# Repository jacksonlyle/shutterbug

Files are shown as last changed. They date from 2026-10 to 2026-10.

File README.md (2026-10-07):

# ShutterBug

A 3D-printed transmissive grating spectrograph, built to capture time-series spectra of a vintage flash bulb.

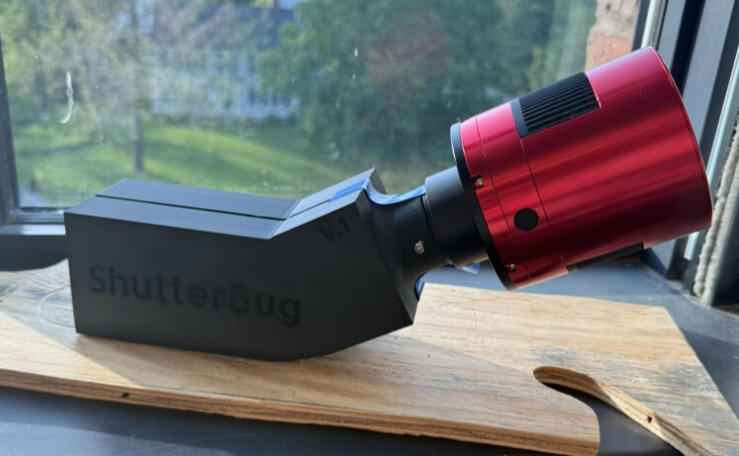
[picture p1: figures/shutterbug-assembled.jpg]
ShutterBug V.1 with a ZWO ASI2600MM Pro attached


The goals for this project were to:

- Create a working spectrograph capable of imaging the visible wavelength range.
- Capture multiple successive spectra of a vintage flash bulb.
- Calibrate and normalize the spectra to identify the bulb's temperature and any absorption lines.

This project was designed around cheap and accessible parts, at the cost of spectral resolution. See
[hardware.md](hardware.md) for the parts list and [docs/reproduce.md](docs/reproduce.md) for build and data reduction steps.

## The Spectrograph

The design began with the transmission grating layout from the Ibsen Photonics
[Spectrometer Design Guide](https://ibsen.com/wp-content/uploads/ebook/spectrometer-resources/Spectrometer-Design-Guide.pdf).
Light enters through a slit, is collimated by a lens, dispersed by the grating, and focused onto the camera sensor.

| Optical path | Design parameters (diagram: Ibsen Photonics) |
|---|---|
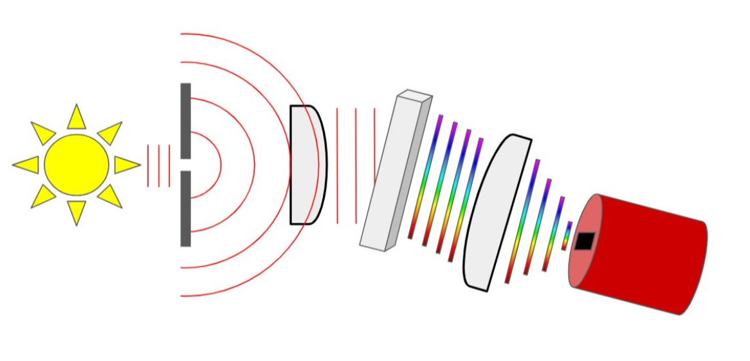
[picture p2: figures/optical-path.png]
Optical path
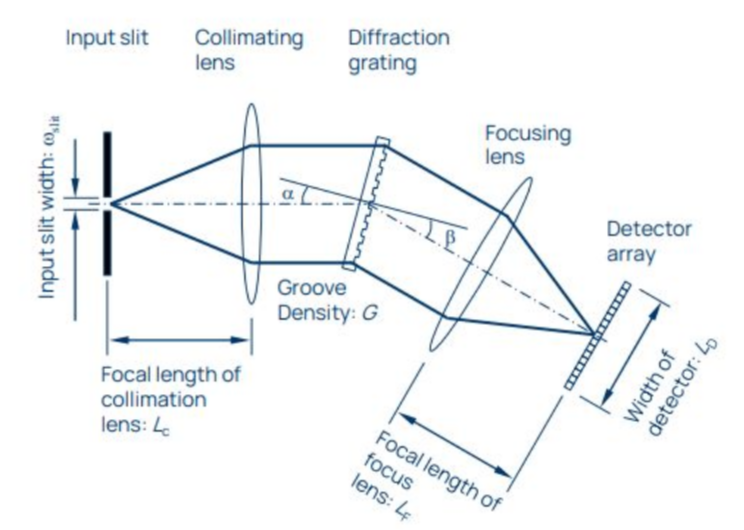
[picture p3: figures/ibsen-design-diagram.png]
Ibsen design diagram
|  |  |

Knowing the size of the camera sensor and my ideal size for the spectrograph, I calculated the distances needed for focus:

| Parameter | Value |
|---|---|
| Groove density, G | 1000 lines/mm |
| Detector width, L_D | 33 mm |
| Angle of incidence, α | 9° |
| Diffraction angle, β | 21° |
| Focus lens focal length, L_F | 103 mm |
| Collimation lens focal length, L_C | 73 mm |
| Slit width, w_slit | 25 µm |

| CAD cutaway | Exterior | Top view |
|---|---|---|
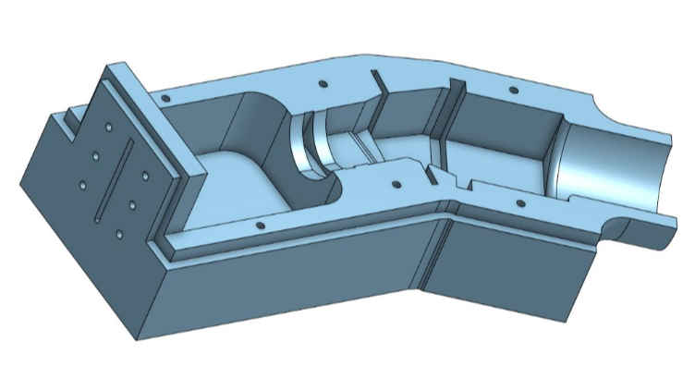
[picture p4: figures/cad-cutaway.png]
CAD cutaway
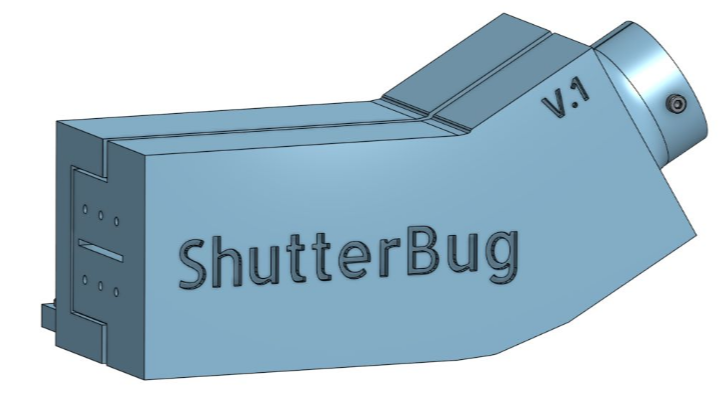
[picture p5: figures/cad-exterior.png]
CAD exterior
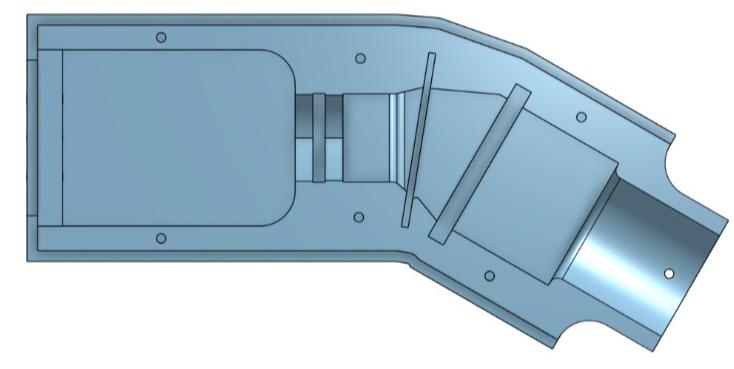
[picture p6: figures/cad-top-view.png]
CAD top view
|  |  |  |

## Obtaining Data

I took data on three sources: the flash bulb itself, a tungsten filament bulb (for flat frames), and an argon emission tube
(for wavelength calibration). SharpCap was used for capture and AstroImageJ for reduction.

The flash lasts approximately 20 ms, and I wanted ~10 individual frames of it. To get there, I imaged a 6248 x 20 pixel
region of the sensor with 1 ms exposures at about 550 FPS. That leaves hundreds of files to sift through, so a short script
kept only the frames above a minimum brightness. I settled on 9 frames of data.

Each light frame was reduced with master bias, dark, and flat frames (100 bias and 100 dark frames were averaged into their masters).

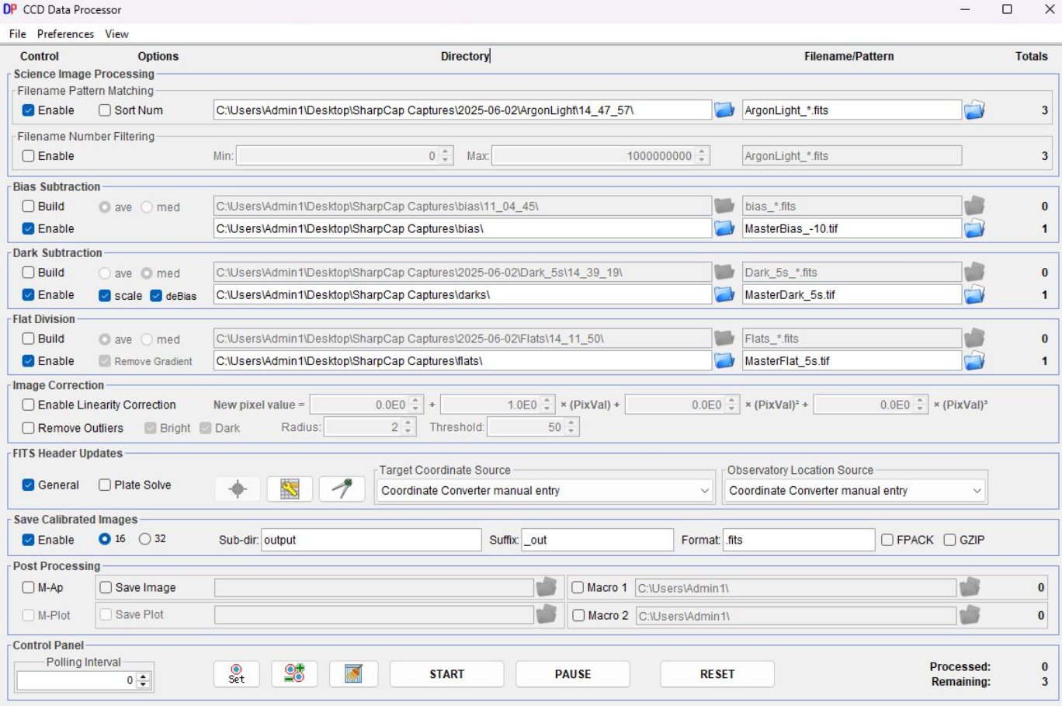
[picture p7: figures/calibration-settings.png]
AstroImageJ CCD Data Processor settings


[spectral_to_csv.py](analysis/spectral_to_csv.py) then averages the central 20 rows of each image into a 1D intensity vs. pixel CSV.

## Calibrating Wavelengths

The argon lamp was dull enough that it needed 5 second exposures instead of 1 ms, so all of the calibration frames had
to be retaken at that length.

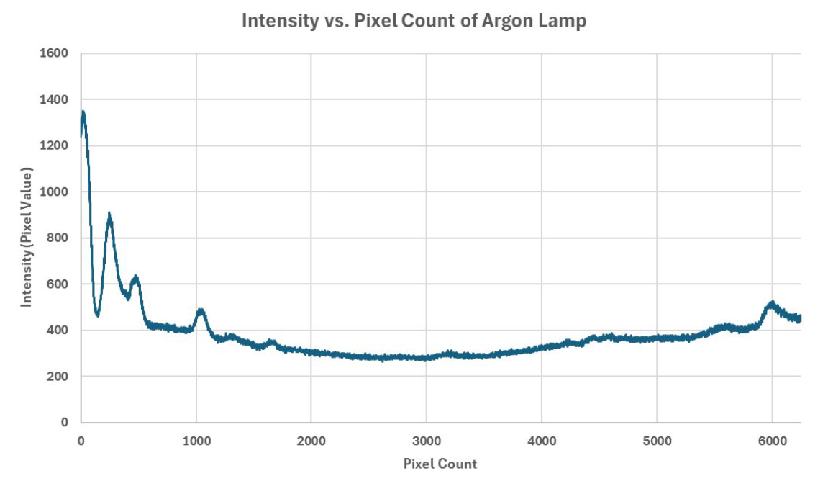
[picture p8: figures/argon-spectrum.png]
Argon lamp intensity vs. pixel count


I identified 7 of the clearest peaks and matched them against Ar I and Ar II lines in the
[NIST Atomic Spectra Database](https://physics.nist.gov/PhysRefData/ASD/lines_form.html). Since the lamp runs at such a high
voltage, it's fair to assume a mixture of neutral and singly ionized argon lines. This gave a (very approximate) linear conversion:

```
wavelength (nm) = 0.06411 * (pixel) + 426.73
```

which puts the spectrograph's range across all 6248 pixels at **426.73–827.29 nm**, a large portion of the visible range.

## Results

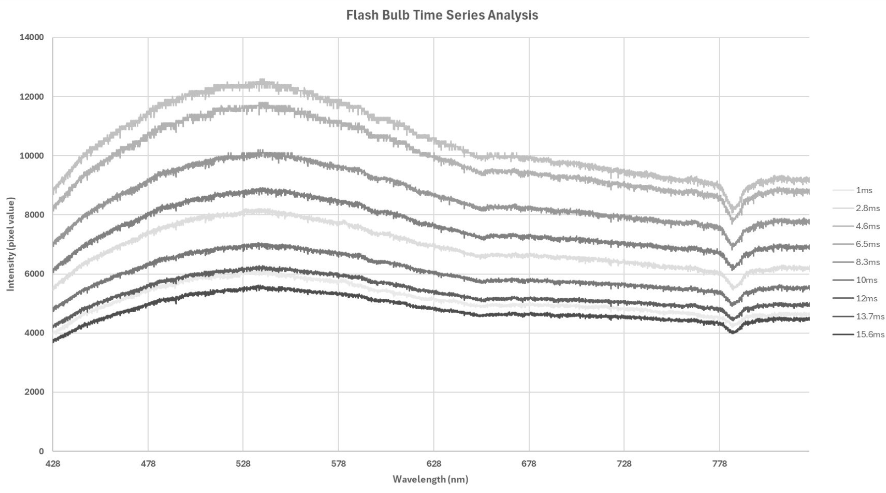
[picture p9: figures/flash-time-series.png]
Flash bulb time series, 1 ms to 15.6 ms


- **Blackbody curve.** Each frame fits a smooth blackbody curve. Using Wien's law on the peak, I estimated a temperature of
  **5470 K**, very close to commonly cited flash bulb values (though sources vary).
- **Time evolution.** The flash brightens over the first few milliseconds, then lowers in intensity and
  flattens. The peak shifts slightly to the right over time, indicating a small drop in temperature over the period of the flash.
- **Absorption.** There are a few small absorption bands and one large broadband absorption region around 780 nm. Based on
  atmospheric absorption data, this matches the O₂ band (the oxygen A-band, ~760 nm), meaning the oxygen in the air between the bulb
  and the slit is absorbing that region. The offset from 760 nm is likely the calibration error described below.

## Sources of Error

- **Quantum efficiency.** I assumed the camera's sensitivity is uniform across wavelengths, when in reality it follows a curve.
  This directly affects the shape of the spectrum, and therefore the Wien's law temperature.
- **Linear calibration.** I assumed the pixel-to-wavelength conversion was linear, when it is closer to a quadratic fit. This was
  apparent in the O₂ band appearing at a longer wavelength than expected.
- **Stray light.** Room lights were on for some of the data capture. I covered any gaps in the spectrograph, but stray light could
  still affect the data.
- **Line identification.** I assumed all argon emission lines were Ar I or Ar II. Other lines in the spectrum would shift the
  conversion and could account for the discrepancy with the measured atmospheric absorption.

The original raw frames and CSVs from this run were not preserved, so the figures above are from the original analysis and the
repository includes the code and build files rather than the data.

## Repository

```
cad/        STEP and STL files for the top plate, bottom plate, and mounting bracket
analysis/   spectral_to_csv.py and requirements.txt
docs/       reproduce.md: build, calibration, and reduction steps
figures/    images used in this README
hardware.md parts list and specifications
```

## Acknowledgements

Thanks to Masaki Muneyoshi for help with the spectrum extraction script.

## Sources

- Ibsen Photonics, [Spectrometer Design Guide](https://ibsen.com/wp-content/uploads/ebook/spectrometer-resources/Spectrometer-Design-Guide.pdf)
- NIST, [Atomic Spectra Database](https://physics.nist.gov/PhysRefData/ASD/lines_form.html)
- [Wien's law](https://boyce-astro.org/wiens-law/), Boyce Research Initiatives and Education Foundation
- ZWO, [ASI2600MM Pro](https://www.zwoastro.com/product/asi2600/)
- FAU, [How the greenhouse effect works](https://www.ces.fau.edu/nasa/module-2/how-greenhouse-effect-works.php)

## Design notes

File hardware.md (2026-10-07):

## Hardware specifications

### Parts List

This project was designed for implementation with cheap and accessible parts, at the cost of spectral resolution.
Most parts for the original project were obtained in a high school physics lab storage, but alternatives can be purchased
from vendors online.

#### Transmissive Grating

The transmissive grating used for this spectrograph was a standard physics lab 1000 lines/mm grating (dimensions fit 
any grating around 50 x 50 x 2 mm in footprint).

#### Lenses 

Based on the geometry of the design, the focal length of the focus lens is 103mm, and the focal length of the collimation
lens is 73mm. 

The focus lens is made for a 50 x 50 x 5 mm footprint lens, and the collimation lens is made for a 25 x 25 x 3.5 mm foorprint lens.

#### Camera

The current camera adapter fits standard 1.25" T mount adapter, available for most DSLR and CCD/CMOS cameras.

PLEASE NOTE: This design was optimized for the ZWO ASI2600MM Pro dimensions and backfocus. You can see details for
the design of this camera and adjust the exact position of a different camera relative to these dimesions: https://www.zwoastro.com/product/new-asi2600mm-mc-pro/ (see "Mechanical Diagram")

#### Fasteners

All of the fasteners are fit for M3 screws:

- 6: M3 x 0.50 x 30
- 6: M3 x 0.50 x 8 (for razor slit)
- 6: M3 x 0.50 nuts
- 2: M3 x 0.50 x 8 (thumbscrews for Camera T Mount)
- Optional for mounting bracket:
    - 4: M3 x 0.50 x 12
    - 4: M3 x 0.50 x [any length, depending on mounting surface]

Note that without the mounting bracket, the weight of the camera will most likely make the spectrograph uneven on a flat surface.

#### Razor slit 

The slit for this spectrograph was designed to work with standard shaving razor blades. The optimal width of the slit is 25 micrometers,
but this does not (and will likely not) be exact.

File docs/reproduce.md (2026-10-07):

## Steps to reproduce

### Creating the spectrograph

All necessary files are included in the [cad directory](../cad/). The cad files are agnostic to specific 3D printers, however
the original print was done with a Bambu Labs printer. Ideally, you should plan to include some kind of surface to which
you can mount the mounting bracket to, as it ensures that the spectrograph stays still. For the original design, this was a 
small sheet of plywood.

After printing at least the top and bottom plates, it is advised to first pre-install all necessary M3 screws using form tapping
to create the threads in the plastic. This step makes it much easier to assemble once the optical compenents are in place.

Place the transmissive grating and optical elements into the respective slots. Note that orientation matters for the collimating
and focus lenses. Ensure that both lenses have the round edge facing the transmissive grating. It can be useful to use small pieces
of foam or filler to ensure a snug fit for the lenses and grating. Try to ensure that each element is centered in the optical train.
Attach the 2 razors on the inside of the front plate, oriented such that you can just barely see light passing through. Make sure 
that both razors are parallel to each other. Then use the short M3 screws and nuts to secure each razor in place.

Once all of the elements are secured in the bottom plate, attach the top plate using the pre-threaded M3 screw holes. Ensure that
the light-trap guards are overlapping around the full spectrograph to ensure no light-leakage. 

Finally, insert the camera using a 1.25" T mount adapter and use 2 M3 thumbscrews to secure it in place. Optionally, you can 
now mount the whole system to the mounting bracket.

### Obtaining Calibration Data 

To create properly reduced final data, you need to have the following sets of frames:

- Light Frames (your actual data)
- Bias Frames (zero second exposures that capture small flaws in the camera sensor)
- Dark Frames (exposures where no light is allowed to come in to identify bias within the camera's own heat signature)
- Flat Frames (an evenly illuminated light source to detect local differences along the sensor)

Obtaining bias frames is trivial with most acquisition software. This project used the free tier of SharpCap imaging software,
which includes functionality for bias frame acquisition. Dark frames can be obtained by simply covering the imaging train with 
a blanket or other object to ensure that no light gets in, then taking exposures at the same intervals of the Light Frames.

For the Flat frames, I used the spectra of a tungsten bulb lamp taken through the spectrograph to act as a standardized blackbody 
emission. This was done by simply pointing the spectrograph at a powered tungsten lamp, then tkaing a series of images such that the
mean pixel value was about half-max, or around 30,000-40,000 pixel value with a 16bit sensor. 

Additionally, for spectral calibration it is required to have a standard emitter. For this project, an Argon lamp was used to 
identify the known peaks and calibrate the pixel-to-wavelength relationship.

### Obtaining Light Frames 

Once you have all necessary calibration data, you can image the desired target spectra. An example was done with an old-fashioned
magnesium flash bulb. For time-series analysis, consider taking images in continuous mode at frequent intervals to capture the spectra 
against time. 

Note that it is helpful to use a dark room when imaging, allowing for minimal external light to leak into the system and blur out 
the source signal. 

### Reducing the Data 

#### Creating Master Calibration Frames 

The standard approach for image reduction is to use multiple of each type of calibration frame and average the pixel values into 
one "Master" frame for each frame type. This is easily done in software like AstroImageJ, which has it's own data reduction pipeline.
I highly recommend following a walkthrough guide on astronomical image reduction, as this project uses the same steps. This guide will 
assume that you have a set of Master Darks, Flats, and Bias frames at this point and have fully reduced all Light frames.

#### Plotting Light frames 

To visualize the FITS image data as a 2d plot, this project uses a simple [python script](../analysis/spectral_to_csv.py) to average 
the central 20 rows of pixels into a 1d csv array. This allows for easy plotting of pixel column v. Intensity. More sophisticated 
methods are welcomed, but not necessary due to the target resolution of this design. Whatever method you choose, ensure that you 
have a set of 1d arrays for both the calibration sample data (such as an argon emission), and the actual light frames (such as the flash bulb emissions). 

#### Calibrating wavelenghts 

In this project, the pixel-to-wavelength conversion was done manually through plotting and selecting emission lines on the calibration 
data (argon emission), and comparing to known emission lines. A simple polynomial fit was then found and used to convert the pixel counts. 
This process was not perfect, and more sophisticated methods are available through python packages and other mediums.

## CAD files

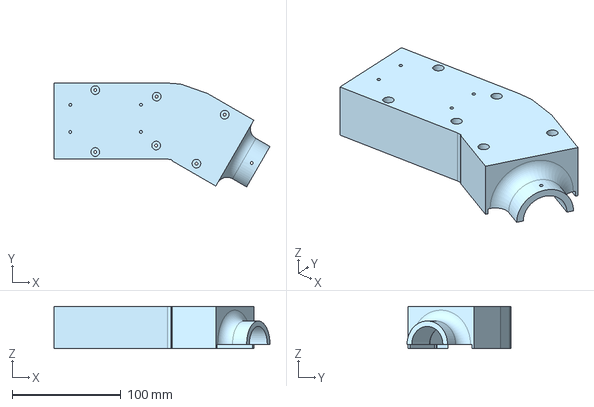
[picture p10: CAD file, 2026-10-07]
cad/bottom_plate.step
198.8 x 95.6 x 39.0 mm

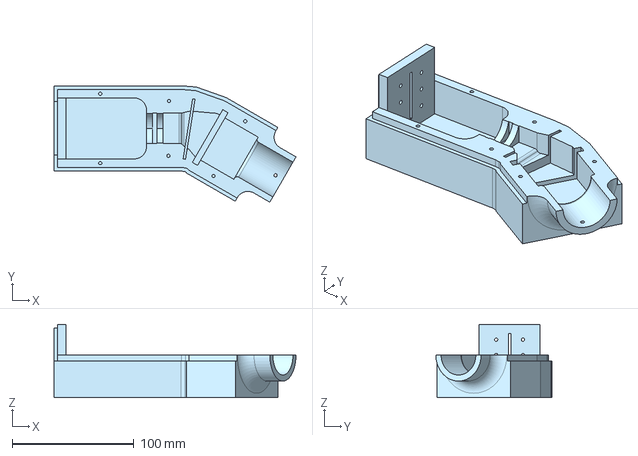
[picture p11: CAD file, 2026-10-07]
cad/mounting_bracket.step
198.8 x 95.6 x 60.0 mm

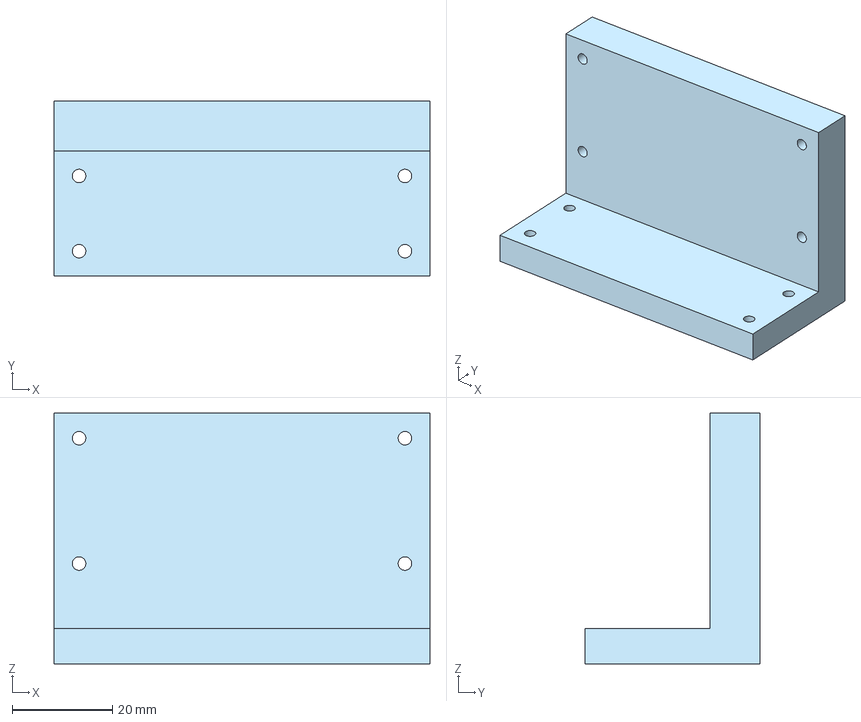
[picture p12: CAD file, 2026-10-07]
cad/top_plate.step
75.0 x 35.0 x 50.0 mm

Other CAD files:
cad/bottom_plate.stl
cad/mounting_bracket.stl
cad/top_plate.stl
